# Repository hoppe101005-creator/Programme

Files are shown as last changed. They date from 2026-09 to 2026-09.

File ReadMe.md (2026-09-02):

# T4_1000 Alexander Hoppe
    Test von Elektromotoren als Alternative zum Bestehenden Motor in Kraft-
    spannblöcken und Nullpunktspannsystemen

# Benutzungsfreigabe
    Dieses Repository darf ausschließlich zur Bewertung durch die DHBW 
    Ravensburg oder zur weiteren Arbeit durch die H.-D. SCHUNK GmbH & 
    Co. Spanntechnik KG. gelesen und benutzt werden. 

# Gliederung des Repositories
    3D Druckdateien Vorrichtung:
        Hier sind alle Dateien für den 3D-Druck des Versuchsaufbaus abgelegt

    Datenblätter:
        Hier liegen alle Datenblätter, die im Laufe der Arbeit benutzt wurden

    Dokumentation:
        Hier liegen die eigentliche T4_1000 mit beiden Praxisreflektionen als 
        PDF und eine Übersicht der Motoren, die während der Arbeit in der 
        engeren auswahl waren

    Programme:
        Hier liegt das vollständige Programm zur ansteuerung der verschie-
        denen Motoren über die EPOS4-Steuerung
    
    Rohdaten Messung sofern aufgenommen:
        Hier sind Screenshots aus dem Pythonprogramm, Aufnahmen der Ströme 
        mit dem Oszilloskop und eine Zusammenfassung aller Messdaten

# Voraussetzungen
    Software:
        Python 3.14
        PyGame 
        Epos Studio

    Hardware:
        Umgebautes NSE-E mini 90-25 IOL mit Motoratrappe und Prüfstand
        Laptop mit Ethernet-Schnittstelle
        SPS mit Funktionsbaustein zum Sensordaten auslesen
        Messglocke
        Oszilloskop
        Netzgerät 24V

# Verwendung
    Clone das Repository und arbeite ausschließlich in deinem lokalen 
    Repository. Passe die lokalen Speicherorte im Code an.
    Baue den Versuch auf und Starte das Programm mit der Datei Visu.py.

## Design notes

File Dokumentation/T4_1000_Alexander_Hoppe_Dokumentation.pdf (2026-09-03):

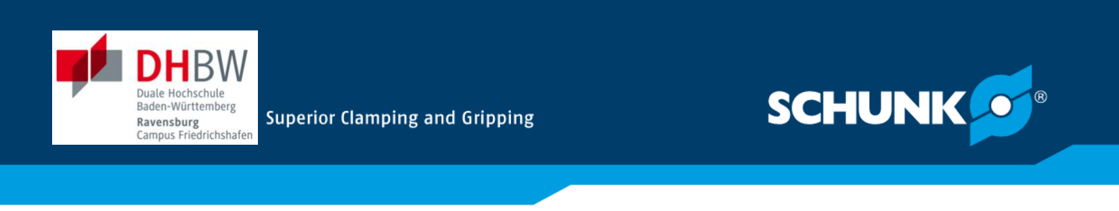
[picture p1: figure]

PRAXISBERICHT

## Test von Elektromotoren als Alternative zum beste-

## henden Motor in Kraftspannblöcken und Null-

## punktspannsystemen

des Studienganges Elektrotechnik und Informationstechnik – Automation

an der Dualen Hochschule Baden-Württemberg Friedrichshafen

von

Alexander Hoppe

05.10.2026

Bearbeitungszeitraum | 9 Wochen
Matrikelnummer, Kurs | 6516453, TEA-25
Dualer Partner | H.-D. SCHUNK GmbH & Co. Spann- technik KG Lothringer Str. 23 88512 Mengen
Betreuer*in des Dualen Partners | B. Eng. Matthias Soziev

T4_1000

II

## Sperrvermerk

Gemäß Ziffer 1.1.13 der Anlage 1 zu §§ 3, 4 und 5 der Studien- und Prüfungsordnung

für die Bachelorstudiengänge im Studienbereich Technik der Dualen Hochschule Ba-

den-Württemberg vom 29.09.2017 in der Fassung vom 25.07.2018:

„Der Inhalt dieser Arbeit darf weder als Ganzes noch in Auszügen Personen außerhalb

des Prüfungsprozesses und des Evaluationsverfahrens zugänglich gemacht werden,

sofern keine anders lautende Genehmigung vom Dualen Partner vorliegt.“

Mengen, den 03.09.2026

Alexander Hoppe

III

## Eidesstattliche Erklärung

Gemäß Ziffer 1.1.13 der Anlage 1 zu §§ 3, 4 und 5 der Studien- und Prüfungsordnung

für die Bachelorstudiengänge im Studienbereich Technik der Dualen Hochschule Ba-

den-Württemberg vom 29.09.2017.

Ich versichere hiermit, dass ich meine Bachelorarbeit (bzw. Projektarbeit oder Studi-

enarbeit bzw. Hausarbeit) mit dem Thema:

Test von Elektromotoren als Alternative zum bestehenden Motor in

Kraftspannblöcken und Nullpunktspannsystemen

selbstständig verfasst und keine anderen als die angegebenen Quellen und Hilfsmittel

benutzt habe. Ich habe bei der Erstellung der Arbeit KI-Werkzeuge eingesetzt. Dies

habe ich an den entsprechenden Stellen der Arbeit kenntlich gemacht.

Mengen, den 03.09.2026

Alexander Hoppe

IV

## Kurzfassung

Ziel dieser Projektarbeit ist es, das erlernte Wissen der ersten und zweiten Theorie-

phase mit den praktischen Inhalten zu verknüpfen und anzuwenden, aber auch gene-

rell über den Inhalt der beiden Praxisphasen zu berichten. Die erste Praxisphase war

zum Teil ein Grundkurs im Umgang mit Metall in der Lehrwerkstatt, in dem das Feilen,

Gewindebohren, Sägen und weitere maschinelle Bearbeitungsarten von Stahl vermit-

telt wurden. In der zweiten Praxisphase durfte ich in der Entwicklung mitarbeiten und

den Versuch zum Tittel dieser Arbeit durchführen.

Im ersten Teil dieser Arbeit werde ich das Unternehmen SCHUNK vorstellen, auf die

Entstehung, Geschichte, und Produktpalette eingehen, damit ein Gefühl für das Un-

ternehmen entsteht.

Anschließend liegt der Fokus auf den erlernten Fertigkeiten aus der Lehrwerkstatt im

Bereich Trennen, wie zum Beispiel das Drehen und Fräsen. Den Kern dieser Arbeit

bildet der Versuch zur Ermittlung verschiedener Alternativen zum aktuell verbauten

Maxon-Motor im Nullpunktspannsystem NSE-E mini 90-25 IOL. Hierbei wird bei einem

bestehenden Exemplar der Motor ausgebaut und die zu testenden Motoren über einen

eigens dafür entworfenen Versuchsaufbau an das Nullpunktspannsystem angebaut.

Ziel des Versuchs ist es, über die Spannkraftmessung die Eignung des Motors zu zei-

gen.

Eine Auflistung meiner Tätigkeiten in den ersten beiden Praxisphasen bei SCHUNK

bildet den Abschluss dieser Arbeit. Diese zeigt auf, welche Fähigkeiten während dieser

Zeit eingesetzt und welche Kompetenzen vermittelt wurden.

V

## Abstract

The aim of this project report is to link and apply the theoretical knowledge acquired

during the first and second semesters with practical experiences, as well as to review

the content of both practical phases. The first practical phase included a basic me-

talworking course in the training workshop, covering filing, tapping, sawing, and various

mechanical machining processes for steel. During the second practical phase, I colla-

borated with the research and development department and conducted the experiment

central to this paper.

The initial section of this report introduces SCHUNK, detailing its origins, history, and

product portfolio to provide comprehensive insight into the company. Subsequently, the

focus shifts to manufacturing skills acquired in the workshop, particularly in machining

processes such as turning and milling.

The core of this work consists of an experiment designed to evaluate various alterna-

tives to the currently installed Maxon motor in the NSE-E mini 90-25 IOL zero-point

clamping system. In this process, the motor of an existing unit is removed, and the test

motors are connected to the clamping system using a custom-designed experimental

setup. The objective of the experiment is to demonstrate the suitability of the alternative

motors through precise clamping force measurements. A detailed list of my activities

during the first two practical phases at SCHUNK concludes this report, highlighting the

skills deployed and competencies developed over this period.

VI

## Inhaltsverzeichnis

Abbildungsverzeichnis | VIII
Tabellenverzeichnis | IX
Verzeichnis von Abkürzungen, Formeln, Formelzeichen und Maßeinheiten | X
Abkürzungen | X
Formeln | X
Formelzeichen | X
Maßeinheiten | XI

VII

7 Anhang | A

VIII

## Abbildungsverzeichnis

Abbildung 15: Diagramm: Spannkräfte der verschiedenen Motoren, eigene Darstellung

Abbildung 16: Diagramm: Messwerte der Motorströme beim Spannen, eigene Darstel-

Abbildung 17: Diagramm: Messwerte der Maximalströme beim Lösen, eigene Darstel-

IX

## Tabellenverzeichnis

Tabelle 2: Messwerte des Maximalstroms beim Spannen, eigene Darstellung ........ 28

X

## Verzeichnis von Abkürzungen, Formeln, Formel-

## zeichen und Maßeinheiten

Abkürzungen

CAD | Computer-Aided Design / Computerunterstütztes Konstruieren
CNC | computerisierte numerische Steuerung
KI | Künstliche Intelligenz
RJ45 | registered Jack
u. A | unter Anderem
USB | universal serial Bus

Formeln

Formel 1: Drehmomentkonstante (Dr. Fritz Faulhaber GmbH & Co. KG 2026)........ 21

Formel 3: Drehzahl-Drehmoment-Kennlinie (Dr. Fritz Faulhaber GmbH & Co. KG 2026)

Formelzeichen

I | Strom
kM | Drehmomentkonstante
kn | Drehzahlkonstante
M | abgegebenes Drehmoment
MA | mögliches Anlaufdrehmoment
n | abgegebene Drehzahl
n0 | Leerlaufdrehzahl

XI

U | Spannung

Maßeinheiten

〖min〗^(-1)/V | Umdrehungen pro Minute/Volt
A | Ampere
M | Hinweis auf metrisches Gewinde
mm | Millimeter
s | Sekunde
V | Volt
W | Watt

## 1 Das Unternehmen SCHUNK

1.1 Die Historie

In Lauffen am Neckar kaufte sich Firmengründer Friedrich Schunk 1945 eine Dreh-

bank, auf der er Ersatzteile für Maschinen fertigte. Als erste Produktionsstätte diente

eine umgebaute Garage, in der er durch einige hochwertige und langlebige Erfindun-

gen, wie eine Lampenschirm-Lochmaschine, schnell bekannt wurde. Durch seine cle-

vere Art bekam er zusätzlich Aufträge, wie die Fertigung in anderen Betrieben zu opti-

mieren. So wurde bei Schunk „Geht nicht, gibt’s nicht“ zu einer Kernkompetenz

(SCHUNK SE & Co. KG 2026).

1964 wurde Schunk von NSU mit der Serienfertigung von 3000 Kupplungstrommeln

und Schwungscheiben für den NSU-Prinz 4 beauftragt und zog mit seiner Produktion

in einen großen Hallenneubau am heutigen Standort in Lauffen am Neckar. Von dort

an war sein Sohn Heinz-Dieter Schunk auch im Unternehmen und baute einen eigenen

Vertrieb für die Produkte von Schunk auf. Mit diesem Vertrieb gab es eine Plattform,

für die ab 1966 produzierten Standartbacken für Drehfutter (SCHUNK SE & Co. KG

2026).

Durch weitere Erfindungen, wie die Hydrodehnspanntechnik im Werkzeughalter Tendo

oder die Werkzeugspannung durch Verformung mit Hilfe der Polygonspanntechnik im

Werkzeughalter Tribos, entwickelte sich das Unternehmen zu einem kompetenten

Partner für Werkzeugspannung in der Metallverarbeitenden Industrie (SCHUNK SE &

Co. KG 2026).

Dem aktuellen Firmeninhaber Heinz-Dieter Schunk war und ist bewusst, dass man nur

durch Neuentwicklungen vorankommt. Mit diesem Grundgedanken im Hinterkopf be-

merkte Schunk auf einer Messe im Jahr 1982, dass die damaligen Greifer an den Ro-

botern zu schwer waren, und entwickelte daraufhin eigene, leichtere Greifer. Mit dieser

Entwicklung stieg SCHUNK in den zukunftsweisenden Bereich der Automation ein.

1989 entschied man sich bei SCHUNK in den Bereich der stationären Spanntechnik

einzusteigen und entwickelte hierbei das erfolgreiche TANDEM-System der Kraft-

spannblöcke (SCHUNK SE & Co. KG 2026).

Die ersten Niederlassungen im Ausland, intern als Intec bezeichnet, wurden 1989 in

Belgien und der Schweiz gegründet. In den 1990er Jahren ergab sich die Möglichkeit

durch einen steigenden Absatz in Nordamerika, einen weiteren Produktionsstandort in

Raleigh, der Hauptstadt von North Carolina, zu eröffnen (SCHUNK SE & Co. KG

2026).

1994 übernahm SCHUNK die Hage GmbH in Mengen und erweiterte somit die Pro-

duktpalette um die Drehfutter und deren Patente, die bis heute Anwendung in den Pro-

dukten des Unternehmens finden (u. A. Backenschnellwechsel im Rota THW 3)

(SCHUNK SE & Co. KG 2026).

2006 ergab sich die Möglichkeit in Hangzhou, China, ein Werk für den dortigen Markt

zu eröffnen. Die deutschen Qualitätsstandards und Ansprüche wurden allerdings nicht

erfüllt, sodass das Werk drei Jahre später geschlossen wurde. Im Gegenzug wurde

die bestehende Niederlassung in Shanghai zu einem Vertriebsstandort ausgebaut (Wi-

kipedia-Autoren 2025).

Die Magnetspanntechnik ist durch die Beteiligung mit 49% am italienischen Unternehmen S.P.D. seit 2008 Bestandteil von SCHUNK. Mit der vollständigen Übernahme von

S.P.D. vertreibt SCHUNK unter deren Namen weiterhin Magnetspanntechnik (Wikipe-

dia-Autoren 2025).

Mit einem neuen Slogan „Superior Clamping and Gripping” hielt 2012 ein neuer Mar-

kenbotschafter, der Ex-Nationaltorhüter Jens Lehmann, bei SCHUNK Einzug und be-

warb für sieben Jahre diverse Produkte von SCHUNK. Hierbei stand die Perfektion der

Produkte und Lösungen im Vordergrund. Mit einem neuen Slogan „Hand in Hand for

tomorrow“ liegt ab 2022 der Fokus auf der Automation und der Zusammenarbeit von

Mensch und Maschine als Zukunftstechnologien.

2014 übernahm SCHUNK das Schweizer Unternehmen Gressel, welches mechani-

sche Spannmittel produziert. Auch diese Marke besteht bis heute (Wikipedia-Autoren

2025).

Nach Baubeginn 2019 wurde das Werk Mengen 2020 mit der Produktionshalle 4 und

dem Entwicklungsgebäude um rund 50% vergrößert. 2022 kam die Mensa hinzu, in der die Mitarbeiter und Besucher am Standort täglich mit frisch zubereitetem Essen

versorgt werden (Joost 2025).

1.2 Werte der Firma SCHUNK

Die Firma Schunk steht für folgende Werte (SCHUNK SE & Co. KG 2026):

Klarheit

Kümmerer-Kultur

Pioniergeist

Qualität

Wertschätzung

Zuverlässigkeit

Klarheit:

Mit einem Überblick über den Markt und dem Blick nach vorn lösen wir die Probleme

der Zukunft.

Kümmerer-Kultur:

Wir kümmern uns um unsere Kunden, bis sie endgültig zufrieden sind

Pioniergeist:

SCHUNK setzt durch Entwicklungen neue Maßstäbe in den Bereichen, von denen wir

Ahnung haben. Darum machen wir nicht alles, aber was wir machen, meistern wir mit

Bravour.

Qualität:

Weil wir unsere Produkte für jahrelange Standzeiten in den Produktionen unserer Kun-

den entwickeln, hat Qualität oberste Priorität. Dahinter stecken viel Erfahrung und Wis-

sen aus jahrelanger Produktion und der Ansporn, immer besser zu werden.

Wertschätzung:

Bei SCHUNK stehen die Maschinen im Mittelpunkt, die Menschen aber an erster

Stelle. Mit gegenseitiger Wertschätzung und gegenseitigem Respekt arbeitet hier tag-

täglich jeder mit jedem an unseren Produkten: Hand in Hand for tomorrow

Zuverlässigkeit:

Unsere Produkte sind nur so gut, wie die Menschen, die sie produzieren, vertreiben

und reparieren. Darum setzt SCHUNK auf Verbindlichkeit, Sorgfalt und ein Wort, das

gilt.

1.3 Standorte

Schunk ist ein weltweit vertretenes Unternehmen mit insgesamt rund 3700 Mitarbeitern

in 10 Werken und 34 Ländern, die sich in zwei größere Untergruppen gliedern lassen

(SCHUNK SE & Co. KG 2026). Zum einen gibt es die produzierenden Standorte, zum

anderen die vertreibenden Standorte. Unter den produzierenden Standorten kann man

zusätzlich in Werke und Tochterunternehmen, die dem Standort Lauffen unterstehen,

und Werke, die dem Standort Mengen unterscheiden (Joost 2025):

Hauptsitz: Lauffen am Neckar | Brackenheim-Hausen

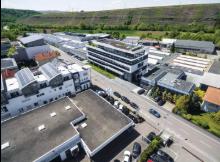
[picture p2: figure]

Abbildung 1: Hauptsitz: Lauffen am

Neckar (SCHUNK SE & Co. KG 2026)

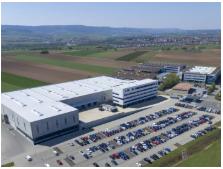
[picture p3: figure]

Abbildung 2: Werk: Brackenheim-Hau-

sen (SCHUNK SE & Co. KG 2026)

Morrisville / North Carolina (USA) | Queretaro (Mexiko)

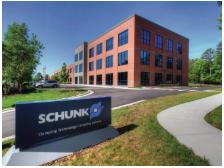
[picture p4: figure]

Abbildung 3: Werk: Morrisville (SCHUNK

SE & Co. KG 2026)

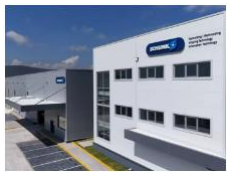
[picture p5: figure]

Abbildung 4: Werk: Queretaro (SCHUNK

SE & Co. KG 2026)

Shanghai (China) | Cleebronn

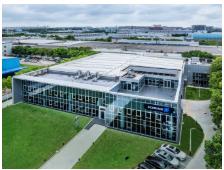
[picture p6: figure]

Abbildung 5: Werk: Shanghai (SCHUNK

SE & Co. KG 2026)

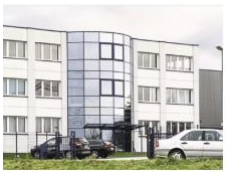
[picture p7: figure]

Abbildung 6: Eberhardt GmbH & Co. KG.

Cleebronn (SCHUNK SE & Co. KG

2026)

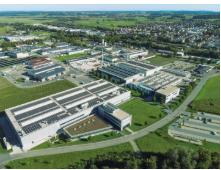
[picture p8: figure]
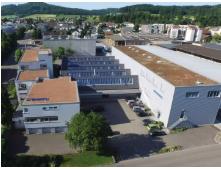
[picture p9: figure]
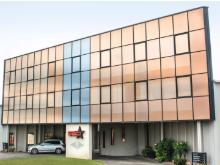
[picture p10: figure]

Zum Vertriebsnetz von Schunk zählen neben den produzierenden Standorten auch die

ausländischen Niederlassungen (Intecs). Allein in Europa gibt es in 38 von 47 souve-

ränen Staaten eine SSCHUNK-Intec oder einen Vertriebspartner. Auch in Asien ist

SCHUNK mit 20 Vertriebsstandorten in 14 Ländern vertreten, um für seine Kunden da

zu sein. Die restlichen 17 Vertriebsstellen verteilen sich auf die beiden amerikanischen

Kontinente, Australien und Südafrika (SCHUNK SE & Co. KG 2026).

Mengen | Gressel AG in Aadorf (Schweiz)

Abbildung 7: Werk: Mengen (SCHUNK

SE & Co. KG 2026)

Abbildung | 8: | Gressel AG: Aadorf

(SCHUNK SE & Co. KG 2026)

S.P.D.-Werk in Caravaggio (Italien)

Abbildung 9: S.P.A.: Caravaggio

(SCHUNK SE & Co. KG 2026)

1.4 Produkte

SCHUNK bietet Produkte in folgenden Bereichen an:

Automatisierungstechnik

Greiftechnik

Nutzentrenntechnik

Werkstückspanntechnik

Werkzeugspanntechnik

In der Automatisierungstechnik bietet SCHUNK eine Vielzahl an Lösungen und

Standardkomponenten an. Wenn es um die Bewegung entlang einer Achse oder um

eine Achse geht, sind die Linearachsen oder die Schwenkeinheiten das Mittel der

Wahl. Damit die Baugruppen nicht überlastet werden, verbaut SCHUNK Kraft-Moment-

Sensoren, die während des Betriebs, zum Beispiel an einem Roboterarm zwischen

Arm und Greifer, die auftretenden Kräfte und Momente messen. In Verbindung mit der Robotersteuerung kann man in diesem Fall eine Überlastsicherung realisieren. An ei-

nem Roboterarm müssen oft verschiedene Greifer für verschiedene Anwendungen an-

gebaut werden - mit den Werkzeugwechslern von SCHUNK kein Problem. Um unter

Bewegung keine Verbindung zu verlieren, gibt es auch Kabeldurchführungen, sowohl

starr als auch schwenkbar. Die Ausgleichseinheiten von SCHUNK kommen immer

dann zum Einsatz, wenn man Abweichungen in Bewegungsabläufen kompensieren

muss. In Kombination mit den SCHUNK-Greifern kann über verschiedene Applikati-

ons-Kits eine lageunabhängige Robotersteuerung realisiert werden, welche:

die Werkstücke greift

an eine rotierende Polierbürste hebt

dort zielgerichtet das Werkstück poliert

anschließend das Werkstück in einer Kiste absetzt

(SCHUNK SE & Co. KG 2026).

Die Greiftechnik wird zum größten Teil in Brackenheim-Hausen gefertigt und dort in

Verbindung mit einem CoLab, einem Vorführungsraum, erprobt und präsentiert. Die

Greifer werden in verschiedenen Formen für verschiedenste Anwendungen entworfen.

Es gibt Parallelgreifer, die mit zwei Fingern entlang einer Achse verfahren, Zentrisch-

greifer, die wie ein Dreibackenfutter einer Drehmaschine mit ihren Fingern das Werk-

stück zentriert greifen, aber auch Winkel-/Radialgreifer, die ihre beiden Finger um ei-

nen fixen Punkt öffnen und schließen. Daneben gibt es Greifer mit Schwenkeinrich-

tung, die sich um ihre eigene Achse bewegen können, und Magnetgreifer, die durch

Elektromagneten magnetische Werkstücke fassen. Hinzu kommen sämtliche Sonder-

greifer und Adhäsionsgreifer, die nach dem Vorbild eines Geckos ihre Werkstücke

sanft und rückstandsfrei greifen (SCHUNK SE & Co. KG 2026).

Nutzen sind große Leiterplatten, die durch Nutzentrenntechniken in kleinere Platinen

geteilt werden. Um diesen Vorgang möglichst effektiv zu gestalten, baut SCHUNK Nut-

zentrenner als Stand-Alone-Lösung, aber auch als Maschinen für eine Produktions-

straße. Damit die Nutzen nicht durch die Maschine beschädigt werden, stellt SCHUNK

zusätzlich auch die passenden Werkstückträger her und das alles in St. Georgen

(SCHUNK SE & Co. KG 2026).

Wenn es um die Werkstückspanntechnik geht, kommt man bei SCHUNK nicht am

Werk Mengen und den Tochterunternehmen Gressel und S.P.D. vorbei. Gressel stellt

die manuell betätigten Spannsysteme, S.P.D. die komplette Magnettechnik und

SCHUNK Mengen die ganzen Drehfutter, Kraftspannblöcke, Nullpunktspannsysteme

und stationären Spannsysteme her. Im weiteren Verlauf werden die Testreihen an ei-

nem elektrisch betriebenem Nullpunktspannsystem durchgeführt (SCHUNK SE & Co.

KG 2026).

Am Hauptsitz in Lauffen wird ein Großteil der Werkzeugspanntechnik gefertigt. Da-

runter fallen Hydrodehnspannfutter, bei denen der Schaft des Werkzeughalters durch

eine Druckkammer verengt wird und das Werkzeug klemmt. Die Polygonspannfutter

funktionieren durch Verformung. Im entspannten Zustand ist der Schaft des Halters

nicht exakt rund, sondern etwas dreieckig. Durch hohen Druck von außen verformt

sich der Schaft zu einem Kreis und das Werkzeug kann eingelegt werden. Anschlie-

ßend nimmt man den Druck weg und das Werkzeug verkanntet sich im Schaft. Die

Drehspannfutter funktionieren über einen Konus, der zusammengedreht wird, sodass

das Werkzeug klemmt. Das Gleiche passiert, wenn ein Warmschrumpffutter von

SCHUNK erhitzt wird, das Werkzeug eingelegt wird und es wieder abkühlt. Die

Spannzangen spannen das Werkzeug über verschiedene konische Einsätze, die vom

Schaftdurchmesser des Werkzeugs abhängen (SCHUNK SE & Co. KG 2026).

## 2 Spanende Fertigungsverfahren

Die verschiedenen Fertigungsverfahren lassen sich nach DIN 8580 in sechs Haupt-

gruppen wie folgt gliedern:

| Beschichten: Aufbringen einer fest haftenden Schicht Fügen: Zwei Bauteile werden miteinander verbunden Trennen: Material wird abgetragen Stoffeigenschaften ändern: Materialeigenschaften werden durch äußere Einflüsse verändert Umformen: Herstellen eines Bauteils allein durch äußere Krafteinwirkung Urformen: Herstellen eines Bauteils durch Erhitzen, in Form füllen und Abkühlen

Ein spanendes Fertigungsverfahren bezeichnet das Abtragen des überschüssigen Ma-

terials von einem Rohteil in Form von Spänen, um ein bestimmtes Maß oder eine vorgegebene Kontur herzustellen und gehört somit in die Hauptgruppe Trennen (Öhler Sj

2022/23).

2.1 Grundbegriffe

Um im weiteren Verlauf die Fertigungsverfahren, die in der Lehrwerkstatt gezeigt wur-

den, erklären zu können, bedarf es an dieser Stelle der Definition einiger Grundbe-

griffe:

Kühlschmierstoff:
Kühlschmierstoffe bestehen meist aus Öl und Wasser und sind dazu da, um bei

Zerspanungen Werkstück und Werkzeugschneide zu kühlen und zu schmieren.

Bei der Schnittbewegung entsteht durch Reibung Hitze, die die Schneide ohne

ausreichende Kühlung zum Glühen bringt und sie stumpf macht. Die Wärme wird primär durch die anfallenden Späne abtransportiert, kann aber auch durch

den Einsatz von Kühlschmierstoffen verringert werden. Mit ausreichender Küh-

lung kann die Wärme abgeleitet und so die Standzeit der Schneide des Werk-

zeugs erhöht werden. Bei leichter Zerspanung liegt der Fokus auf der Kühlung, weshalb man hier auf einen hohen Wasseranteil im Öl-Wasser-Gemisch setzt.

Bei schwerer Zerspanung braucht man die Schmierwirkung des Kühlschmierstoffs und setzt auf einen hohen Öl-Anteil (Brendle 2025).

Schlichtbearbeitung:

Beim Schlichten geht es darum, die endgültigen Maße, Toleranzen und Ober-

flächen herzustellen. Daher verwendet man zum Schlichten oft auch andere

Werkzeuge als zum Schruppen (Brendle 2025).

Schnittbewegung:

Bei einer Schnittbewegung bewegen sich Werkzeugschneide und Werkstück

durch den Vorschub anfangs aufeinander zu, bevor die Schneide in das Werk-

stück eintaucht, Späne bildet und so Material abträgt.

Schnittbreite:

Die Schnittbreite bezieht sich auf die Position des Werkzeugs relativ zur Posi-

tion des Werkstücks. Konkret: Wie weit taucht die Schneide meines Werkzeugs

entlang der Werkstückoberfläche in das Werkstück ein (Hanser Sj 2022/23).

Schnittgeschwindigkeit:

Unter der Schnittgeschwindigkeit versteht man die Geschwindigkeit, die die

Schneide am entferntesten Punkt zum Werkzeugmittelpunkt während der

Schnittbewegung hat (Hanser Sj 2022/23).

Schnitttiefe:

Die Schnitttiefe bezieht sich auf die Position des Werkzeugs relativ zur Position

des Werkstücks. Konkret: Wie weit taucht die Schneide meines Werkzeugs

senkrecht zur Werkstückoberfläche in das Werkstück ein (Hanser Sj 2022/23).

Schruppbearbeitung:

Beim Schruppen liegt das Hauptaugenmerk auf dem schnellen Abtragen es

überschüssigen Materials. Daher kann man hier mit ungenaueren Werkzeugen

arbeiten (Brendle 2025).

Standzeit:

Die Standzeit bezeichnet die Lebensdauer eines Werkzeugs oder in diesem

Zusammenhang die Lebensdauer einer Schneide (Brendle 2025).

Vorschub:

Der Vorschub bezeichnet die Bewegung, die der Werkzeugmittelpunkt relativ

zum Werkstück entlang der zu bearbeitenden Kontur hat (Hanser Sj 2022/23).

Wendeschneidplatten:

Eine Wendeschneidplatte ist ein flaches Element mit mehreren Schneiden zur

Befestigung auf einem Werkzeug. Durch die vielen Schneiden ist es möglich

die Wendeschneidplatte, bei Verschleiß einer Schneide, zu drehen und sie so

länger zu nutzen.

Werkstücknullpunkt:

Der Werkstücknullpunkt ist ein Referenzpunkt, von wo aus das Werkstück be-

maßt wird. Er wird nach dem Einspannen des Rohlings in der Maschine einge-

messen, und muss mit dem Nullpunkt der Zeichnung übereinstimmen. Andern-

falls muss der Werkstücknullpunk so verschoben werden, dass er dem Null-

punkt der Zeichnung entspricht (Brendle 2025).

Zerspanbarkeit:

Die Zerspanbarkeit bezeichnet die Widerstandsfähigkeit eines Werkstoffs wäh-

rend der Zerspanung. Sie hängt von unterschiedlichen Faktoren, wie den Werk-

stoffeigenschaften, ab und zeigt sich in der Oberflächengüte, Standzeit der

Werkzeuge und am Brechen der Späne (Brendle 2025).

Zustellung:

Als Zustellung wird das Maß bezeichnet, das während des Arbeitsgangs durch

die Späne verloren geht (Brendle 2025).

2.2 Drehen

Das Drehen ist eines der essenzielle Fertigungsverfahren im Maschinenbau, da hier

sehr leicht Rotationskörper bearbeitet werden können. Hierbei trägt eine feststehende

Werkzeugschneide eine vorgegebene Kontur entlang eines rotierenden Werkstücks

ab, sodass die zweidimensionale Kontur als Rotationskörper entsteht. Die

Rotationsachse ist durch das Drehfutter der Drehbank vorgegeben. Hierbei kann nicht

immer sofort auf das Endmaß der Kontur zugestellt werden, da jedes Werkzeug mit

jedem Werkstoff unterschiedlich interagiert und die Schneide, selbst unter Verwen-

dung des Kühlschmierstoffs, oft überhitzen würde. Daher nimmt man einen Großteil

der Späne mit der Schruppbearbeitung ab und stellt den Rest in mehreren Schritten

mit der Schlichtbearbeitung zu. Die Schneidewerkzeuge werden oft als Drehmeißel

bezeichnet und sind in der Regel mit einer Wendeschneidplatte an der Spitze bestückt.

Durch die einzelne Schneide findet eine kontinuierliche Spanabnahme statt, was in der

Lehrwerkstatt sichtbar wurde. Auch bei SCHUNK stehen viele Drehmaschinen, die

meisten mit einer CNC-Steuerung, um zum Beispiel die Rohlinge der Drehfutter oder

Werkzeughalter zu fertigen.

2.3 Fräsen

Das Fräsen ist auch essenziell für die Fertigung im Maschinenbau, da hier ebene Flä-

chen und gerade Kanten sehr leicht hergestellt werden können. Hierbei wird das Werk-

stück auf dem Tisch der Fräsmaschine eingespannt und ein Fräser, das Schneidwerk-

zeug der Fräse, bewegt sich mit Hilfe des Vorschubs relativ zum Werkstück durch das

Werkstück. Bei CNC-gesteuerten Fräsmaschinen hinterlegt man eine Zeichnung und

den Werkstücknullpunkt, wonach die Fräsmaschine eine Art Laufkarte errechnet und

diese abfährt. Bei konventionellen Maschinen erledigt das der Bediener. Auch hier

schruppt man zuerst die groben Konturen, bevor man sie schlichtet. Wie beim Drehen

kann man durch Einsatz von Kühlschmierstoffen die Standzeit des Fräsers bezie-

hungsweise die Standzeit der Wendeschneidplatten des Fräsers verlängern. Fräsen

haben, im Unterschied zu den Drehwerkzeugen, immer mehrere Schneiden für einen

ruhigeren Lauf. Als Faustformel kann man sagen: Je genauer das Maß oder die Ober-

fläche, desto mehr Schneiden. Die Schneiden sind immer gleichmäßig über die Stirn-

seite verteilt und schlängeln sich entlang der Mantelfläche des Fräsers hinauf zum

Schaft des Fräsers. Das hat zur Folge, dass jede Schneide innerhalb einer Umdrehung

einmal aus dem Werkstück aus- und einmal in das Werkstück eintritt. Dadurch kann

sich kein kontinuierlicher Span bilden. Fräsmaschinen sind ein sehr großer und wichtiger Bestandteil der Produktion bei SCHUNK, da auf diesen Maschinen sämtliche

Körper von Produkten gefertigt werden.

2.4 Bohren

Das Bohren ist dem Fräsen sehr ähnlich, weil auch hier der Bohrer rotiert, um den

Span aus dem Bohrloch zu schneiden und das Werkstück fixiert ist. Der Vorschub zeigt

entlang der Achse des Bohrers, der durch seine Geometrie eine kontinuierliche Span-

abnahme ermöglicht. Ein Spiralbohrer, das Schneidwerkzeug beim Bohren, verfügt

über drei Schneiden, die punktsymmetrisch über sie Bohrspitze verteilt sind: Die Quer-

schneide verläuft senkrecht zum Bohrerschaft durch den Mittelpunkt der Bohrspitze

und bohrt im Durchmesser rund ein Drittel des Materials des Bohrdurchmessers um

den Mittelpunkt auf. Die restlichen zwei Drittel des Bohrlochs verteilen sich zu je einer

Hälfte auf eine Hauptschneide. Die Hauptschneiden stehen in einem bestimmten Win-

kel zum Schaft, nicht senkrecht wie beim Fräser, und haben zusätzlich einen Winkel

zur Querschneide bei der Projektion aller drei Schneiden auf die Ebene, die senkrecht

zum Schaft des Bohrers verläuft. Zusätzlich besitzt er zwei Nebenschneiden, die sich

entlang der Wendel von der Spitze zum Schaft schlängeln. Mit Bohrern werden Löcher

mit definierten Durchmessern hergestellt, die bestimmte Toleranzen, sowohl im Durch-

messer als auch in der Oberflächengüte der Mantelfläche, haben. Möchte man ein

Loch mit einer höheren Maßhaltigkeit, muss man das Loch kleiner vorbohren und an-

schließend reiben.

2.4.1 Reiben

Das Reiben ist eine spezielle Form des Bohrens, mit dem Ziel eine bestehende Boh-

rung mit einem genormten Maß auf ein größeres genormtes Maß zu weiten. Hierbei

liegt der Fokus auf der Maßhaltigkeit und der Oberflächengüte der Bohrung, die man

benötigt, um eine Passung herzustellen. Die Schnittgeschwindigkeit von Bohrern wird

beim Reiben halbiert, da hier ein ruhiger Lauf für die Maßhaltigkeit entscheidend ist.

Der Bohrer beim Reiben wird als Reibahle bezeichnet und es gibt ihn in mehreren

Ausführungen:

Mehrschneidig, nicht einstellbar

Mehrschneidig, einstellbar im Durchmesser

Einschneidig mit Führungsleiste, einstellbar im Durchmesser

2.4.2 Senken

Auch das Senken ist eine Art des Bohrens, nur wird hierbei ein Profil an der Stirnseite

einer bestehenden Bohrung hinzugefügt. Die gängigsten Anwendungen sind Kegel-

senkungen oder Zylindersenkungen. Bei Kegelsenkungen wird mit einem Kegelsen-

ker, ein mehrschneidiger Bohrer mit einem Kegel als Profil, bis zu einer definierten

Tiefe in das Loch gebohrt. Durch die Kegelform zentriert er sich selbst. Bei einer Zy-

lindersenkung hat man die Form eines Bohrers, dessen Spitze senkrecht zur Bohrer-

achse abgeschnitten und ihm ein Zentrierdorn in der Mitte aufgesetzt hat. Damit die

Zylindersenkung konzentrisch zur Bohrung ist, besitzt der Zylindersenker zusätzlich

einen Zentrierbolzen an der Stelle der Querschneide eines Bohrers. Darüber hinaus

sind weitere Konturen möglich, aber äußerst selten.

## 3 Messen

3.1 Was ist messen?

Definition nach DIN 1319-1 (Manghard 2026):

Messen ist das Ausführen von geplanten Tätigkeiten zum quantitativen Vergleich der

Messgröße mit einer Maßeinheit

3.2 Warum misst man?

Die Ingenieursweisheit „Wer misst, misst Mist“ geht auf Murphys-Gesetz zurück und

verdeutlicht, dass eine einzelne Messung meist nicht ausreicht, um ein zuverlässiges

Ergebnis zu erhalten. Ein einzelner Messwert kann durch Messfehler beeinflusst wer-

den und somit stark vom theoretischen Wert abweichen. Deshalb sollte man mehrere

Messungen durchführen und die Ergebnisse miteinander vergleichen. Aus mehreren

Messwerten lässt sich ein Bereich bestimmen, in dem der tatsächliche Wert liegt. Je

mehr sorgfältige Messungen vorgenommen werden, desto zuverlässiger und genauer

wird das Ergebnis (Manghard 2026). Liegen nur wenige Messwerte vor und weichen

diese stark voneinander ab, lässt sich kaum beurteilen, welcher Wert dem tatsächli-

chen Wert am nächsten kommt. Genau auf diese Unsicherheit spielt die Weisheit „Wer

misst, misst Mist“ an.

3.3 Messmittel

Messmittel sind Messwerkzeuge zur Ermittlung eines Messwerts. Jedes Messmittel

besitzt eine Auflösung und einen Messbereich:

Auflösung:

Als Auflösung wird der Abstand zwischen zwei benachbarten, kleinstmöglichen

Messwerten bezeichnet. Abhängig von der geforderten Genauigkeit der Mes-

sung erfolgt die Wahl des Messmittels (Manghard 2026).

Messbereich:

Der Messbereich eines Messmittels beschreibt den Bereich, in dem alle

Messwerte des Messmittels liegen (Manghard 2026).

3.3.1 Messschieber

Der Messschieber ist im Maschinenbau ein grundlegendes Messmittel, um Längen von

Strecken zu messen. Ein Messschieber misst nach der Ausschlagmethode. Dabei ver-

schiebt sich die bewegliche Messbacke (Abbildung 10: Standardmessschieber, (Wiki-

media 2023)) entlang einer Skala (Abbildung 10: Standardmessschieber, (Wikimedia

2023)Ziffer 4) und die Nullmarkierung, beziehungsweise die Noniusskala (Abbildung

10: Standardmessschieber, (Wikimedia 2023)Ziffer 6) erzeugt den Ausschlag. Duch

eine spezielle Anordnung der Noniusskala, kann man hiermit bei einem analogen

Messschieber eine Auflösung von 0,1 mm erzielen. Bei digitalen Messschiebern funk-

tioniert das ganze nach dem gleichen Prinzip, nur über einen elektronischen Weg-

sensor. Das Signal des Wegsensors wird anschließend in die gewünschte Maßeinheit

umgerechnet. Die meisten digitalen Messschieber verfügen über eine Nulltaste, mit

der man einen neuen Referenzpunkt bei einem bestimmten Maß setzen kann, wenn

man zum Beispiel nur die Differenz zweier Längen haben möchte und nicht das abso-

lute Maß. Messschieber gibt es in verschiedenen, an diverse Anwendungen ange-

passte, Bauformen:

Standardmessschieber:

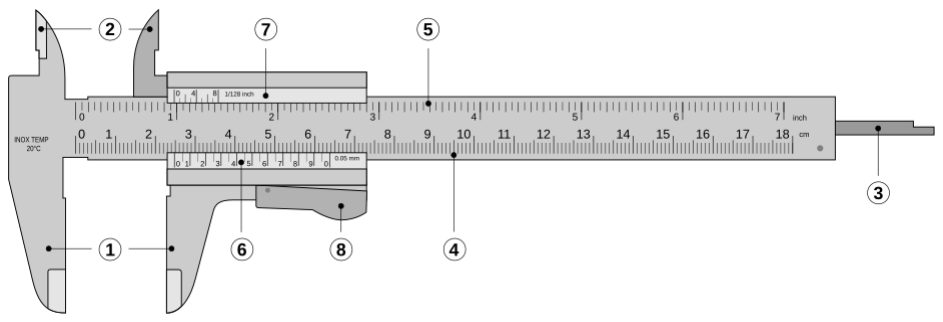
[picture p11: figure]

Abbildung 10: Standardmessschieber, (Wikimedia 2023)

Der Standardmessschieber hat drei Möglichkeiten Längen zu messen: Es gibt

an dem festen und dem losen Teil je zwei fixe Backen, ein Paar für die

Längenmessung außerhalb des Bauteils (Abbildung 10: Standardmessschie-

ber, (Wikimedia 2023)), das andere für die Längenmessung innerhalb des Bau-

teils (Abbildung 10: Standardmessschieber, (Wikimedia 2023)). Die dritte Mög-

lichkeit ist der Messdorn auf der Unterseite (Abbildung 10: Standardmessschie-

ber, (Wikimedia 2023)Ziffer 3). Mit ihm kann man einen Falz oder die Tiefe einer

Bohrung oder einer Nut vermessen (Brendle 2025).

Tiefenmessschieber:

Mit dem Tiefenmessschieber misst man Längen zwischen einer Ebene und ei-

nem Punkt durch ein Loch in der Ebene. Dabei setzt man den Tiefenmessschie-

ber mit dessen Füßen auf der Ebene auf und lässt den Messdorn auf den zu

messenden Punkt fallen (Brendle 2025). Das gleiche kann man auch mit einem

Standardmessschieber machen. Die Messung ist allerdings nicht so genau, weil

der Standardmessschieber eine kleinere Auflagefläche auf der Ebene hat und

man so leichter verwackelt.

3.3.2 Bügelmessschraube

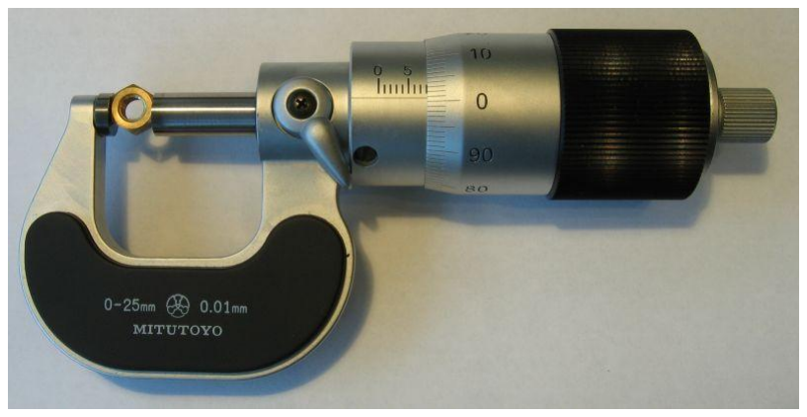
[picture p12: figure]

Mit der Bügelmessschraube misst man

Strecken um Bauteile herum mit einer

höheren Auflösung als mit einem Mess-

schieber, weil die Bügelmessschraube

anders aufgebaut ist. Die Bügelmess-

schraube misst auch nach der Aus-

schlagmethode und funktioniert über ei-

nen Messbolzen, der durch ein festste-

hendes Außengewinde gedreht wird. Da-

bei verfährt der Bolzen bei einer Umdrehung um einen durch die Gewindesteigung definierten Wert. Über zwei Skalen kann man den Messwert ablesen: Entlang des

Messbolzen ist die grobe Skala zur Bestimmung der Messgröße im Millimeterbereich

aufgetragen. Durch das Verdrehen des Bolzens bewegt sich eine Art Hülse über die

Außenseite des feststehenden Gewindes. Auf der Mantelfläche dieser Hülse ist die

Abbildung 11: Bügelmessschraube, (wiki-

media 2010)

feinere Skala mit einer höheren Auflösung zur Feinbestimmung abgebildet (Abbildung

11: Bügelmessschraube, (wikimedia 2010)). Den Messwert liest man ab, indem man

den groben Wert am Rand der Hülse und den feinen Wert durch Verlängerung des

Fluchtstrichs der Grobskala auf die Feinskala abliest. Mit einer normalen Bügelmess-

schraube erreicht man eine Auflösung von 0.01 mm (Brendle 2025).

3.3.3 Multimeter

Zum Messen verschiedener elektrischer Größen ist das Multimeter das Mittel der

Wahl. Mit ihm lassen sich zum einen verschiedene Spannungen und Ströme, aber

auch Widerstandswerte ermitteln. Das Multimeter besitzt drei Anschlüsse, von denen

bei jeder Messung zwei benutzt werden. Bei einer Spannungsmessung liegt auf einem

Anschluss das Referenzpotential, auf dem anderen Anschluss das zu messende Po-

tential. Bei einer Strommessung wird gezählt, wie viel Ladung pro Zeit fließt, daher

benötigt man bei einer Strommessung auch beide Anschlüsse. Den Anschluss für das

zu messende Signal wählt man in Abhängigkeit des Messbereichs, die Masse ist aber

immer belegt. Bei der Widerstandsmessung finden intern beide anderen Messungen

statt und das Messgerät verrechnet nur die Einzelwerte miteinander (Gerster 2026).

3.3.4 Oszilloskop

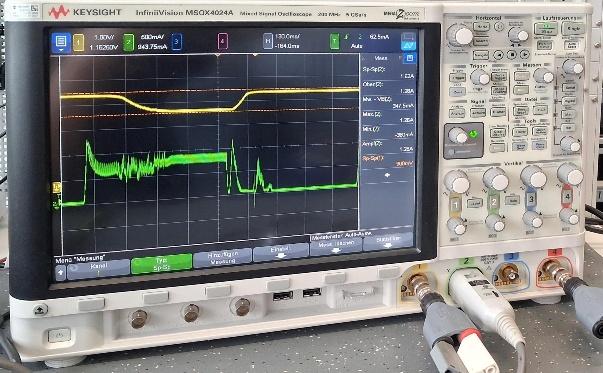
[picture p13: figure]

Mit dem Oszilloskop lassen sich Spannungs-

verläufe beobachten und analysieren. Das Os-

zilloskop braucht für jedes Signal ein Signalpo-

tential und ein Referenzpotential, da die Span-

nung immer eine Potentialdifferenz ist. Nun

wird das Signal auf dem Bildschirm in einem

u(t)-Diagramm angezeigt und man kann zu

verschiedenen Zeiten verschiedene Span-

nungswerte ablesen. Wenn das Gerät mehrere

Signaleingänge hat, kann man die einzelnen Signale übereinanderlegen, um Abwei-

chungen festzustellen. Falls das Signal einer Funktion ähnelt, können manche

Abbildung 12: Oszilloskop, eigene

Darstellung

Oszilloskope eine Näherungsfunktion bestimmen, mit der man rechnen kann (Gerster

2026).

3.3.5 Hall-Sensor

Um den Hall-Sensor zu verstehen, muss man zuerst verstehen, was der Hall-Effekt ist.

Fließt Strom durch einen Leiter, erzeugt er ein kreisförmiges Magnetfeld um den Leiter.

Ist dieser Leiter flexibel in einem anderen homogenen Magnetfeld, werden durch die

Lorenzkraft die Elektronen im Leiter bewegt, weil sich beide Felder überlagern.

Dadurch, dass die Elektronen nicht aus dem Leiter heraus können, bewegt sich der

Leiter senkrecht zur Stromrichtung und zum homogenen Magnetfeld. Tauscht man den

Leiter gegen einen Quader und fixiert diesen, so kann man die Bewegung der Elektro-

nen als Hall-Spannung messen (Dr. Hellwig Sj 2023/24). Diesen Effekt nutzt ein Hall-

Sensor, um die Lage eines Magnetfelds und dessen Stärke zu bestimmen. Diese Sen-

soren nutzt man in bürstenlosen Gleichstrommotoren, um die Lage des Magnetfelds

zu bestimmen und anschließend die Kommutation, also die Umpolung des Magnet-

felds innerhalb eines Motors, zu steuern.

3.3.6 Piezoelektrische Sensoren

Sensoren, die den piezoelektrischen Effekt nutzen, können äußere Kräfte in ein Span-

nungssignal umwandeln, weil sie im Inneren eine Kristallstruktur besitzen. In dieser

Struktur gibt es Elektronen und Protonen, die sich durch ihre unterschiedliche Ladung

anziehen und so zwei Ladungsschwerpunkte innerhalb des Kristalls bilden. Wird der

Kristall durch eine Kraft verformt, verschieben sich die Ladungsschwerpunkte und es

entsteht eine sehr kleine Spannung innerhalb eines Kristalls (FWU Institut für Film und

Bild in Wissenschaft und Unterricht gemeinnützige GmbH 2026). Durch Skalieren vie-

ler Kristalle verstärkt sich der Effekt und es entsteht eine messbare Spannung. Mit

dieser Art Sensor wird im weiteren Verlauf die Einzugskraft und somit die Eignung der

verschiedenen Motoren überprüft.

## 4 Motorversuch

4.1 Problemstellung

In den elektromechanischen Nullpunktspannsystemen von SCHUNK werden aktuell

Motoren verbaut, die vom Zulieferer Maxon ausschließlich an schon bestehende Kun-

den und nicht mehr an Neukunden verkauft werden. Daher vermuten wir, dass die

Produktion dieser Motoren auf Dauer eingestellt wird und das Nullpunktspannsystem

einen neuen Motor braucht (Briemle 2026). Das Problem ist nur, dass es wenige bürs-

tenlose „Motoren von der Stange“ gibt, die genügend Leistung haben, aber trotzdem

in das Produkt integriert werden können. Das Schwierigste dabei sind die Höhe des

Motorkörpers, der Wellendurchmesser und die Flanschmaße der anderen Hersteller.

4.2 Aufbau und Funktion des Nullpunktspannsystems

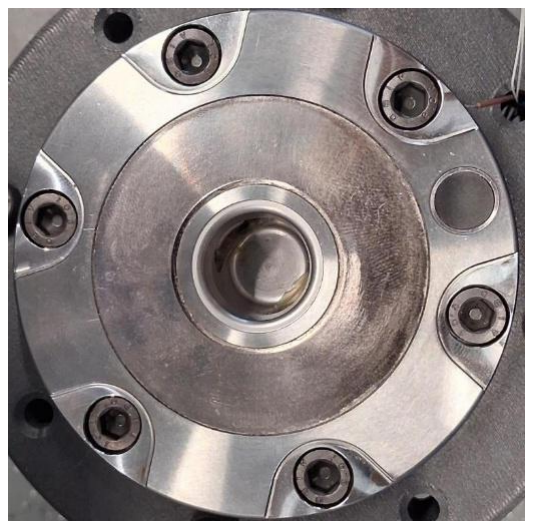
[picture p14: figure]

Über das Spannloch in der Mitte der Oberseite

nimmt das Nullpunktspannsystem einen Spann-

bolzen auf und spannt diesen über zwei Spann-

schieber. Durch die geometrische Form von

Spannschieber, Spannloch und Spannbolzen

kann der Spannbolzen mit rund 3kN eingezogen

werden (SCHUNK SE & Co. KG 2026).

Das Nullpunktspannsystem (Abbildung 13: Null-

punkspannsystem, eigene Darstellung) wird aktu-

ell von einer Baugruppe, bestehend aus einem

bürstenlosen Flachmotor mit 50W und einem Zykloidgetriebe von SCHUNK mit einer Übersetzung von 1:400 angetrieben. Der Abtrieb

des Getriebes ist mit einer Scheibe, in welche eine Kurvenbahn eingefräst ist, verbun-

den. Auf dieser Scheibe sind zwei geführte Bolzen, die beim Verdrehen der Scheibe

entweder öffnen oder schließen und den Spannbolzen des zu spannenden Objekts

einziehen. Das heißt, dass mit jeder Umdrehung sich die Spannkraft erhöht. Möchte

man nun eine vorgegebene Spannkraft erreichen, muss man die entsprechende

Abbildung 13: Nullpunkspann-

system, eigene Darstellung

Position der geforderten Spannkraft herausfinden. Daher wird im folgenden Versuch

die Position in ganzen Umdrehungen angegeben.

4.3 Spezielle Kennwerte eines Motors

Jeder Motor hat seine eigenen charakteristischen Eigenschaften, wonach man ver-

schiedene Motoren vergleichen kann. Einige davon sind ausschlaggebend für den Ver-

wendungszweck in den verschiedenen Produkten. In diesem Fall geht es hauptsäch-

lich darum, viel Kraft zu erzeugen. Dafür braucht man ein hohes Drehmoment, was

durch die Drehung der Kurvenbahn in eine Kraft umgewandelt wird. Dieses Drehmo-

ment entsteht durch Lorenzkraft. Die Lorenzkraft beschreibt die Kraft, die in einem

stromdurchflossenen Leiter in einem Magnetfeld gemäß der Linken-Hand-Regel auf

ein Elektron wirkt. Dabei zeigt der Daumen den Elektronenfluss, also von Minus nach

Plus, der Zeigefinger entlang der Magnetfeldlinien, von Nord nach Süd, und der Mittel-

finger zeigt in die Richtung der resultierenden Lorenzkraft. Kurz gesagt: Das Drehmo-

ment des Motors entsteht aus der Elektronenbewegung, also aus dem elektrischen

Strom. Um diese Umwandlung quantitativ vergleichen zu können, gibt es die Drehmo-

mentkonstante. Diese Drehmomentkonstante berechnet sich wie folgt:

Formel 1: Drehmomentkonstante (Dr. Fritz Faulhaber GmbH & Co. KG 2026)

kM =

M
I
kM: | Drehmomentkonstante
M: | abgegebenes Drehmoment
I: | Strom

Je höher dieser Wert ist, um so effektiver ist die Energieumwandlung von elektrischer

Energie über magnetische Energie in kinetische Energie.

Die Drehzahlkonstante ist ein wichtiger Kennwert für die Ansteuerung des Motors, da

sie über das Verhältnis von Spannung zu Drehzahl Auskunft gibt. Durch sie kann man

für jede Leerlaufdrehzahl den dazugehörigen Spannungswert wie folgt berechnen:

Formel 2: Drehzahlkonstante (Dr. Fritz Faulhaber GmbH & Co. KG 2026)

kn =

n
U
kn: | Drehzahlkonstante
n: | abgegebene Drehzahl
U: | Spannung

Je niedriger dieser Wert ist, um so feinfühliger lässt sich die Leerlaufdrehzahl für jede

Spannung einstellen. Natürlich schwindet ein Teil der Drehzahl durch die Belastung im

Arbeitsfall.

Um beide Konstanten miteinander zu verknüpfen, gibt es die Drehzahl-Drehmoment-

Kennlinie. Anhand dieser Kennlinie kann man den Drehzahlabfall bei steigender Last,

also steigendem Drehmoment am Abtrieb des Motors, beschreiben und beobachten.

Diese Kennlinie beginnt bei Leerlaufdrehzahl ohne Lastmoment und endet beim maxi-

malen Anlaufmoment, das der Motor überwinden kann. Rein rechnerisch gibt es zwei

Achsenschnittpunkte, die aber in der Realität durch Reibung und andere Gegebenhei-

ten nicht existieren. Daraus ergibt sich folgende Formel:

Formel 3: Drehzahl-Drehmoment-Kennlinie (Dr. Fritz Faulhaber GmbH & Co. KG 2026)

n = −

∆n
∆M

∗ M + n0

n = −

n0 − n
M

∗ M + n0

Steigungsdreieck aus den Achsenschnittpunkten:

n = −

n0
MA

∗ M + n0

Ausklammern von n0 ergibt:

n = n0 ∗ (1 −

M
MA

)

n: | abgegebene Drehzahl
n0: | Leerlaufdrehzahl
M: | abgegebenes Drehmoment
MA: | mögliches Anlaufdrehmoment

Diese Formel verdeutlicht den Zusammenhang zwischen den beiden Größen und den

theoretischen Achsenschnittpunkten, ablesbar durch die beiden Konstanten Leerlauf-

drehzahl und Anlaufdrehmoment. Diese beiden Achsenschnittpunkte sind nicht mög-

lich, da das Drehmoment aus dem elektrischen Strom und die Drehzahl aus der Span-

nung hervorgeht und beide elektrischen Größen in der Realität, durch reale Bauteile,

nicht getrennt voneinander auftreten können. Daher wird oft in Datenblättern nur die

Steigung dieser Kennlinie angegeben.

Um den Motor vor Überhitzung zu schützen, gibt es Grenzwerte für die Umgebungs-

temperatur, bei der ein Motor betrieben werden darf. Zur Umgebungstemperatur hinzu

kommen zwei verschiedene thermische Zeitkonstanten τ, die Auswirkungen auf die

Temperatur im Motor haben. Die thermische Zeitkonstante des Motors ist ein Maß für

die thermische Trägheit des Motors bei Erwärmung und Abkühlung. Sie gibt an, nach

welcher Zeit sich der Motor um rund 63% erwärmt hat (Dr. Fritz Faulhaber GmbH &

Co. KG 2026). Eine hohe Zeitkonstante bedeutet eine hohe Trägheit und eine lange

Zeit bis der Motor seine Genztemperatur erreicht hat. Da der Graph bis zum Erreichen

der Grenztemperatur einer Exponentialfunktion ähnelt, kann man in Bereich von 0 <

t < 5τ den Graph annähernd durch solch eine Funktion beschreiben. Die gleiche Me-

thode existiert auch für die einzelnen Wicklungen. Da alle Wicklungen innerhalb des

Motors baugleich sind und sich somit gleich erwärmen, wird die Bestimmung nur an

einer Wicklung durchgeführt.

4.4 Auswahl der Motoren

Bei der Auswahl der Motoren gibt es drei Bereiche, die über die Eignung entscheiden:

Anschlüsse:

Der Motor wird mit einer fixen Versorgungsspannung betrieben. Diese Versor-

gungsquelle darf nicht überlastet werden und liefert daher nur einen bestimmten

Strom. Zur Ansteuerung der Kommutation benötigt die aktuelle Steuerung das Signal der Hall-Sensoren im Innenraum des Motors. Über die drei Hall-Senso-

ren bestimmt man die Lage des Magnetfeldes und dadurch die Lage von Rotor

und Stator zueinander. Damit können die einzelnen Spulen so angesteuert wer-

den, dass sich der Motor dreht.

Bauraum:

Der Bauraum entscheidet darüber, ob der Moror an dem vorgesehenen Platz in

die Baugruppe passt. Dafür muss der Flansch zum Fügen des Motors in die

Baugruppe zur Gegenseite des Motors passen.

Spezielle Kennwerte eines Motors:

Die speziellen Kennwerte geben Auskunft über die Umwandlung der elektri-

schen Energie in mechanische Energie.

Das hier benutzten Nullpunktspannsystem von SCHUNK gibt folgende Werte vor

(SCHUNK SE & Co. KG 2026):

Anschlusswerte:

Betriebsspannung: 24V

Maximale Stromaufnahme: 3A

Leistung: rund 45W (Vorgängermotor)

Bauraum:

Durchmesser: <45mm

Länge Motorkörper: <25mm

Lochkreis Flansch: ∅22mm, 3 Gewindelöcher M3 (120° zueinander verscho-

ben)

Welle: ∅4mm

Zentrierdurchmesser: ∅12mm

Spezielle Kennwerte eines Motors:

Drehmomentkonstante: 78.6mNm/A Drehzahlkonstante: 121min⁻¹
/V

Thermische Zeitkonstanten:

Motor: 78.30s

Wicklung: 28.80s

Steigung der Drehmoment-Drehzahl-Kennlinie: 5.58min⁻¹
/mNm

Nach einiger Recherche und ein paar Absprachen habe ich mich für folgende Motoren

entschieden:

ACT 57BL03-1: Bauraum zu klein, aber preiswert

Faulhaber 4221 G024 BXT R: erfüllt alle Voraussetzungen

Delta Line 45BLW21: erfüllt, nach Anpassungen, alle Voraussetzungen

Maxon EC 45 flat (651613), zu ersetzender Motor als Referenz

4.5 Versuchsaufbau

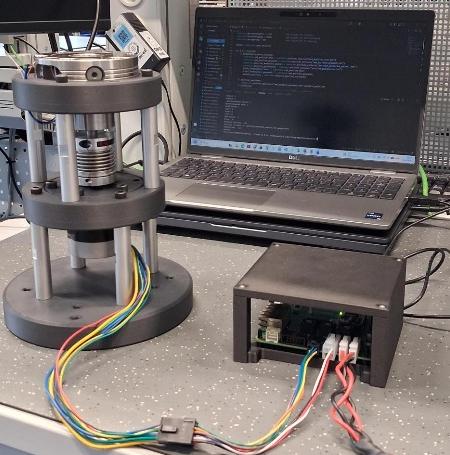
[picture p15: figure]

Für diesen Versuch wird ein NSE-E mini 90-25 IOL mit

einer Motorattrappe zur Verfügung gestellt. Nun wird

eine Vorrichtung in der CAD-Software Creo Parametric

entworfen, 3D-gedruckt und nach Rücksprache mit Sven

Briemle entschieden, eine Kupplung und Abstandshül-

sen als Kaufteil zu erwerben. Durch die verschiedenen

Durchmesser müssen Buchsen gedreht werden, um die

Kupplung kraftschlüssig mit den Wellen der verschiede-

nen Motoren zu verbinden. Die verschiedenen Motoren

werden an dafür konstruierte Flanschplatten ange-

schraubt. Die Einzugskraft wird von einer Messglocke,

ausgebaut aus einem internen Prüfstand, mit dem piezoelektrischen Kistler Kraftmess-

ring 9102C gemessen, der Strom mit der Strommesszange eines Oszilloskops. Zur

Ansteuerung wird die EPOS4 Motorsteuerung und zum Auslesen der Sensordaten, der

Position und der Bedienung ein eigenes Programm in Python verwendet. Um die Mo-

toren mit der Motorsteuerung ansteuern zu können, muss man die passende Steck-

verbindung motorseitig herstellen, die Motorsteuerung mit der Betriebsspannung des

Motors versorgen und sie über USB oder RJ45 / Ethernet mit dem Laptop verbinden.

Abbildung 14: Versuchsauf-

bau ohne Messgeräte, ei-

gene Darstellung

4.6 Erläuterungen zum Vorgehen

Vorab muss gesagt werden, dass die Spannposition der Motoren im Nullpunktspann-

system aktuell über eine Kombination aus dem Strom und der Position definiert wird.

Damit im Versuch gleichbleibende Bedingungen für alle Motoren herrschen, werden

hier die verschiedenen Positionen ausschließlich über die Anzahl der Umdrehungen

definiert. Im folgenden Unterkapitel wird beschrieben, wie man auf die Messfälle

kommt. Die acht Messfälle bilden sich aus drei Parametern, die jeweils zwei Zustände

erreichen können:

Position:

Die Position soll bei allen Motoren im Versuch die gleiche sein, um sie miteinan-

der vergleichen zu können. Daher muss man die Position in Inkrementen in eine

Position in vollständigen Umdrehungen umrechnen. Um die Werte der einzel-

nen Positionen zu ermitteln, dreht wird der Antrieb des Nullpunktspannsystems

händisch von Endanschlag zu Endanschlag gedreht (Geöffnet, Geschlossen).

Möchte man die Zwischenpositionen, dreht man diesen Abtrieb so weit zu, dass

entweder der Spannbolzen sich gerade noch, ohne zu verhaken entnehmen

lässt (Wechsel) oder man mit eingesetzter Messglocke die geforderte Spann-

kraft erreicht (Gespannt).

Drehzahl:

Die Drehzahlen wurden so gewählt, dass sie von den Motoren erreicht werden

und das Nullpunktspannsystem innerhalb von rund drei Sekunden verfährt.

Bremsbeschleunigung:

Die Bremsbeschleunigung wurde so gewählt, dass es keine ruckartigen Ab-

bremsungen gibt und die Motoren trotzdem ruhig anhalten. Damit können de

Positionen genauer angefahren werden.

4.7 Durchführung

Nachdem das Nullpunktspannsystem und der zu testende Motor in der Vorrichtung

platziert wurden, legt man an die Motorsteuerung die Betriebsspannung des Motors

an, hinterlegt die Kennwerte des Motors in der Software der Steuerung und startet das

Python-Programm in einer dafür geeigneten Programmierumgebung. Dort gibt man

Motor, Position der Spannschieber, Drehzahl und die positive / negative Beschleuni-

gung an. Danach kann man durch Klicken auf einen der angezeigten Buttons die

Spannschieber an die programmierten Positionen verfahren. Die Messung der Ein-

zugskraft erfolgt nur während des Spannprozesses. Nach einer Wartezeit von zehn

Sekunden nach Stillstand der Spannschieber endet die Spannkraftmessung und die

Spannschieber fahren wieder auf die Wechsel-Position. Anschließend wird noch zwei

weitere Male gespannt, um mögliche Abweichungen vom ersten Messwert auszu-

schließen. Nach jeder Messung wird die Betriebsspannung abgeschaltet, um jede

Messung unter den gleichen Voraussetzungen durchzuführen. Damit die Einflüsse der

jeweiligen Eingabeparameter getestet werden, durchläuft jeder Motor mehrmals mit

geänderten Parametern diesen Prozess. Getestet werden der Einfluss des Bremsbe-

schleunigung, der Drehzahl und der Position und es ergeben sich folgende Ergeb-

nisse:

Tabelle 1: Messwerte der Spannkraft, eigene Darstellung

Messfall | Position | Drehzahl | Bremsbeschleuni-gung | Spannkraft
| | | | ACT | Faulhaber | Maxon
| [1] [ | 1 ] min | 1 [ ] 2 s | [kN] | [kN] | [kN]
1 | 30 | 1500 | 275 | 2,8 | 2,8 | 2,5
2 | 30 | 1500 | 150 | 2,8 | 2,8 | 2,5
3 | 30 | 1000 | 275 | 2,8 | 2,8 | 2,6
4 | 30 | 1000 | 150 | 2,8 | 2,7 | 2,4
5 | 31 | 1500 | 275 | 3,6 | 3,7 | 3,2
6 | 31 | 1500 | 150 | 3,6 | 3,6 | 3,2
7 | 31 | 1000 | 275 | 3,6 | 3,6 | 3,2
8 | 31 | 1000 | 150 | 3,6 | 3,6 | 3,1

## Spannkräfte

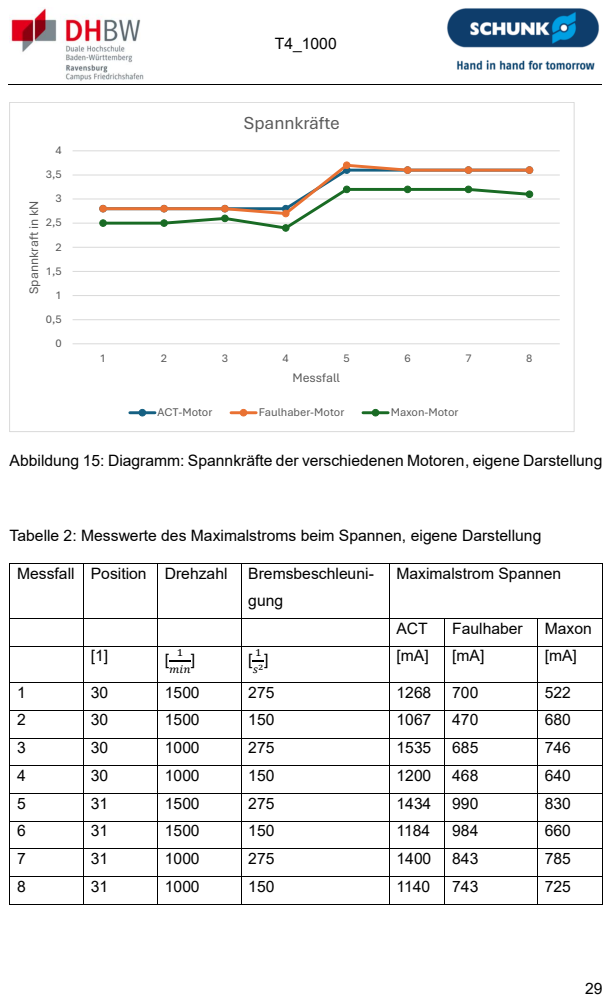
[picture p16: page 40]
Messfall; ACT-Motor; Faulhaber-Motor; Maxon-Motor

Spannkraft in kN

Abbildung 15: Diagramm: Spannkräfte der verschiedenen Motoren, eigene Darstellung

Tabelle 2: Messwerte des Maximalstroms beim Spannen, eigene Darstellung

Messfall | Position | Drehzahl | Bremsbeschleuni-gung | Maximalstrom Spannen

ACT | Faulhaber | Maxon

[1] [ | 1 ] min | 1 [ ] s 2 | [mA] | [mA] | [mA]

1 | 30 | 1500 | 275 | 1268 | 700 | 522
2 | 30 | 1500 | 150 | 1067 | 470 | 680
3 | 30 | 1000 | 275 | 1535 | 685 | 746
4 | 30 | 1000 | 150 | 1200 | 468 | 640
5 | 31 | 1500 | 275 | 1434 | 990 | 830
6 | 31 | 1500 | 150 | 1184 | 984 | 660
7 | 31 | 1000 | 275 | 1400 | 843 | 785
8 | 31 | 1000 | 150 | 1140 | 743 | 725

## Motorströme beim Spannen

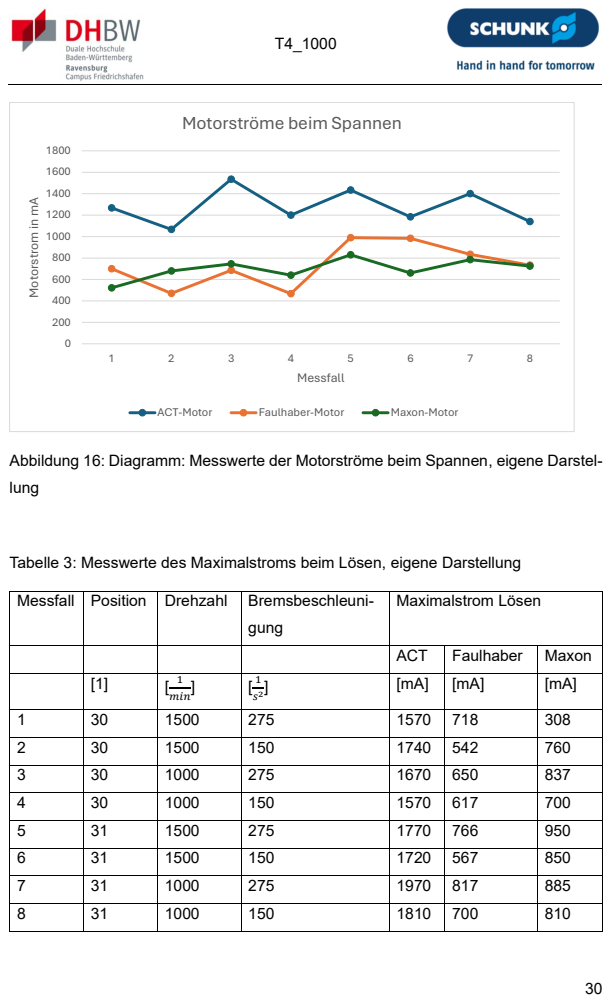
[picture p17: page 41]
Messfall; ACT-Motor; Faulhaber-Motor; Maxon-Motor

Motorstrom in mA

Abbildung 16: Diagramm: Messwerte der Motorströme beim Spannen, eigene Darstel-
lung

Tabelle 3: Messwerte des Maximalstroms beim Lösen, eigene Darstellung

Messfall | Position | Drehzahl | Bremsbeschleuni-gung | Maximalstrom Lösen

ACT | Faulhaber | Maxon

[1] [ | 1 ] min | 1 [ ] s 2 | [mA] | [mA] | [mA]

1 | 30 | 1500 | 275 | 1570 | 718 | 308
2 | 30 | 1500 | 150 | 1740 | 542 | 760
3 | 30 | 1000 | 275 | 1670 | 650 | 837
4 | 30 | 1000 | 150 | 1570 | 617 | 700
5 | 31 | 1500 | 275 | 1770 | 766 | 950
6 | 31 | 1500 | 150 | 1720 | 567 | 850
7 | 31 | 1000 | 275 | 1970 | 817 | 885
8 | 31 | 1000 | 150 | 1810 | 700 | 810

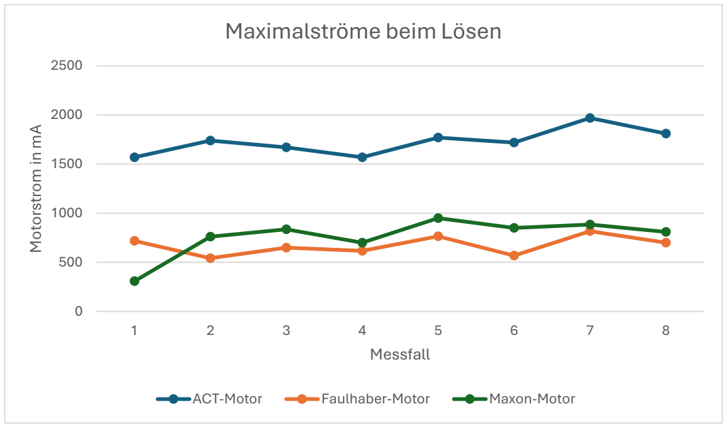
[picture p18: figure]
Motorstrom in mA; Messfall; Maximalströme beim Lösen; ACT-Motor; Faulhaber-Motor; Maxon-Motor

Abbildung 17: Diagramm: Messwerte der Maximalströme beim Lösen, eigene Darstel-

lung

Aus den Diagrammen des Oszilloskops lassen sich durch Integration verschiedene

Fahrströme berechnen. Zur Annäherung an den Graph des Stroms werden verschie-

dene Geraden in das Schaubild gelegt und anhand dieser Geraden integriert. Als

Grundlage dienen die mit dem Oszilloskop aufgenommenen Diagramme der einzelnen

Fälle mit den höchsten Maximalströmen. Die Berechnungen werde ich schrittweise am

Fall 7 während des Lösevorgangs des ACT-Motors durchführen und für die anderen

Fälle nur die Ergebnisse angeben. Die Formel wird anfangs allgemein angegeben und

in den einzelnen Schritten in kleineren Gleichungen genutzt, zuerst allgemein, danach

mit den Werten aus dem Beispiel.

Formel 4: Mittelwert des Integrals einer Geraden

Imittel =

1
t

∗ ∫ (

i(t = 3s) − i(t = 0s)
t

∗ t + i(t = 0s))

t

0

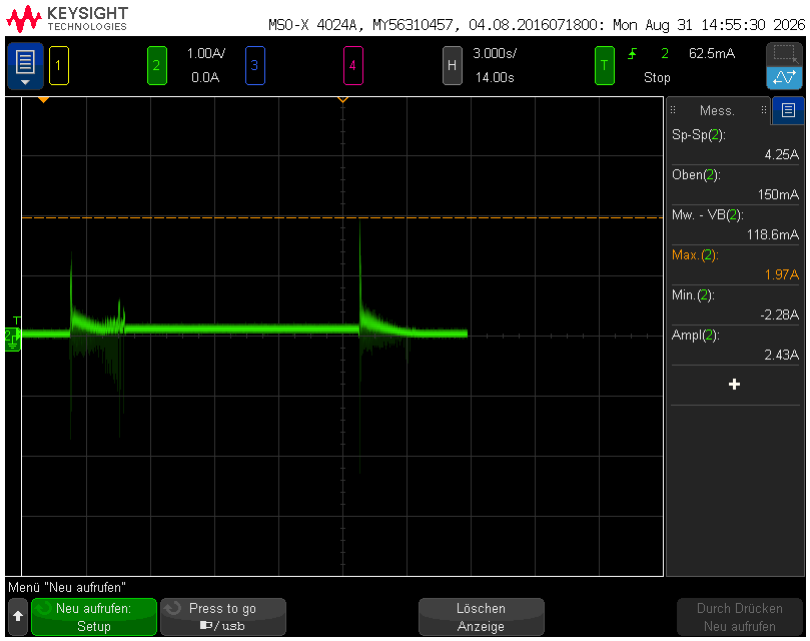
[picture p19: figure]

Abbildung 18: Oszilloskop ACT-Motor Fall 7

1. Werte aus Abbildung 18 ablesen:
t = 3s | i(t = 0s) = 450mA | i(t = 3s) = 160mA
2. i(t) als Geradengleichung bestimmen:

i(t) =

i(t = 3s) − i(t = 0s)
t

∗ t + i(t = 0s)

=

−290mA
3s

∗ t + 450m

3.

4. i(t) nach t integrieren:

I(t) =

i(t = 3s) − i(t = 0s)
2 ∗ t

∗ t

2 + i(t = 0s) ∗ t

=

−290mA
2 ∗ 3s

∗ t

2 + 450mA ∗ t

5. Das bestimmte Integral lösen:

Da die Zeit t aus Schritt 1 vom Ursprung gemessen wurde, entfällt das Einset-

zen der unteren Integrationsgrenze, da diese den Wert Null hat und bei einem

Bestimmten Integral die Integrationskonstante entfällt.

I(3s) =

−280mA
2 ∗ 3s

∗ (3s)

2 + 450mA ∗ 3s

= 915mA ∗ s

6. Den mittleren Strom berechnen:

Imittel =

I(3s)
t

=

915mA ∗ s
2.5s
= 305mA

Tabelle 4: Mittelwerte der Ströme beim Fahren

Motor | Messfall | Aktion | Imittel
| | | [mA]
ACT | 3 | spannen | 685
| 6 | lösen | 305
Faulhaber | 5 | spannen | 485
| 7 | lösen | 200
Maxon | 8 | spannen | 405
| 8 | lösen | 100

4.8 Auswertung

Eine vollständige Auswertung ist zu diesem Zeitpunkt nicht möglich, da der Motor von

DeltaLine noch nicht geliefert wurde und somit noch nicht getestet werden konnte.

Generell fällt auf, dass im Vergleich der Maxon-Motor den Spannbolzen bei jeder Mes-

sung mit einer wesentlich kleineren Spannkraft einzieht als die anderen Motoren im

Versuch. Daher sieht man, dass das Nullpunktspannsystem die erforderliche Spann-

kraft von 3kN mit dem ACT- und dem Faulhaber-Motor bei der richtigen Position (31

Umdrehungen nach der Wechselposition) übertrifft. Wenn man die Differenz der

Spannkräfte des Nullpunktspannsystems kleiner als 0,4kN zur Spannkraft des Refe-

renzmotors haben möchte, muss man die Position der Motoren über Zwischenschritte

innerhalb einer Umdrehung ansteuern. Man muss die Umdrehungen in kleinere

Schritte umrechnen, die mit den Impulsen der Hall-Sensoren zusammenhängen. Um

diesen Umrechnungsfaktor zu bestimmen, ermittelt man die Polpaarzahl, multipliziert

sie mit der Anzahl der Hallsensoren und verdoppelt diesen Wert.

Wenn man sich den Verlauf der Maximalströme in Abbildung 16: Diagramm: Mess-

werte der Motorströme beim Spannen oder in Abbildung 17: Diagramm: Messwerte

der Maximalströme beim Lösen anschaut, erkennt man einen Strom-Sockel bei jeder

Bewegung. Dieser Sockel existiert, weil sich das magnetische Feld zuerst in ausrei-

chender Stärke aufbauen muss, um den Rotor und somit die Welle zu bewegen. Wie

groß das magnetische Feld sein muss, um genügend Kraft für die Bewegung aufbrin-

gen zu können, hängt vom Trägheitsmoment des Rotors ab. Durch die größere Bau-

form des ACT-Motors sind dieses Trägheitsmoment und der daraus resultierende

Stromsockel bei diesem Motor wesentlich größer. Beim Faulhaber-Motor liegt das Ro-

torträgheitsmoment im Rahmen des Rotorträgheitsmoments des Maxon-Motors. Au-

ßerdem betragen die Mittelwerte der Fahrströme beim ACT-Motor rund das 1,5-fache

der gleichen Ströme der anderen Versuchsmotoren Tabelle 4: Mittelwerte der Ströme

beim Fahren.

Die Motoren unterscheiden sich gewaltig im Bauraum. Der ACT ist mehr als doppelt

so lang und besitzt den rund 1,5-fachen Durchmesser des Maxon-Motors. Daher eignet er sich nicht für den Einbau in das bestehende Nullpunktspannsystem. Der Faul-

haber ist kleiner als der Maxon-Motor und kann auch hier punkten. Allerdings sind die

Flanschmaße anders, sodass folgende Flanschflächen im Nullpunktspannsystem an-

gepasst werden müssen: Es müssen auf dem bestehenden Lochkreis weitere Ge-

winde gebohrt werden und der Zentrierdurchmesser muss von 12mm auf 16mm er-

weitert werden.

Daher empfehle ich den Faulhaber-Motor und werde ihn für die weitere Integration in

das Nullpunktspannsystem in Betracht ziehen.

## 5 Tätigkeitsübersicht

Tabelle 5: Tätigkeitsübersicht, eigene Darstellung

Tätigkeit | Abteilung | Zeitraum
Manuelle Grundfertigkeiten: Sicherheitsunterweisung Umgang mit Hilfs-, Mess-, Prüfmitteln und Werkzeugen Feilen, Sägen, Gewindeschneiden Technische Zeichnungen lesen und verstehen Umgang mit Kühlschmierstoffen Fügen durch Schrauben Ordnung und Sauberkeit am Arbeitsplatz | Lehrwerkstatt | KW40/25-42/25
Konventionelle Fertigung: Kenngrößen (Beispiel: Schnittgeschwindigkeit) Einstellen der Maschine Wartung der Maschine Verschleiß von Schneidstoffen Maschinelles Drehen und Fräsen | Lehrwerkstatt | KW43/25-48/25
Vorkurs Physik | DHBW | KW49/25-50/25
Grundlagen der Elektrotechnik: Kennenlernen des zukünftigen Arbeitsumfelds Löten kleiner Projekte (Beispiel: Durchgangsprüfer) Schaltschrank verschlauchen Programmieren eines Arduinos Erster Kontakt mit IO-Link | Entwicklung | KW51/25

Einarbeiten in Ingenieursaufgaben:

Messtechnik

Sensorik

Softwareprüfungen am IO-Link-Prüfstand

Einsatz von Standartsoftware zur Text- und Da-

tenverarbeitung

Beschaffung Kaufteile

Entwurf und Zeichnen eines Versuchsaufbaus

Einarbeitung in Creo Parametic und Zeichnen

von 3D-Druckteilen für den Versuchsaufbau

(4.5)

3D-Druck

Einarbeitung in Epos Studio zur Motoransteu-

erung (4.5)

Programmierung der Ansteuerung des Motor-

versuchs in Python

Entwicklung | KW 27/26-
| 39/26

## 6 Schlusswort

Die Bearbeitung dieser Arbeit war interessant für mich, weil ich Schnittstellen in der

Entwicklung zwischen Elektrotechnikern und Maschinenbauern kennengelernt habe.

Die Einarbeitung in Creo Parametric war für mich überraschend, aber interessant, da

man als Elektrotechniker eigentlich wenig Schnittpunkte mit dem Prozess bis zum fer-

tigen 3D-Druckteil hat. Beim Entwerfen des Prüfstands ist aufgefallen, dass die Spann-

kraftmessung in einem Kraftspannblock in dieser Form nicht möglich ist, da der An-

triebsstrang unvorteilhaft verbaut ist, daher die Messung am Nullpunktspannsystem.

Durch diese Arbeit habe ich auch gelernt, dass man in der Lehrwerkstatt nicht nur zum

Kennenlernen ist, sondern auch hinterher davon profitieren kann. Zu Beispiel habe ich

die Hülsen zwischen der Kupplung und den Motoren selbst gedreht, weil diese bei der

Bestellung untergegangen sind. Bei der Recherche war es hilfreich die heutigen Hilfs-

mittel zu nutzen und dadurch zu lernen, wie man möglichst zielgerichtet Anfragen an

eine künstliche Intelligenz stellt.

Das Programmieren in Python hat mich zum Teil an meine Grenzen gebracht, weil mir

die Erfahrung im Umgang mit solch umfangreichen Programmen gefehlt hat und mir

dadurch erst klar wurde, was alles möglich ist.

Im nächsten Schritt wird der Motor noch ausgiebiger getestet und versucht, den Motor

in das Nullpunktspannsystem zu integrieren und diese Kombination mit dem neuen

Zykloidgetriebe in Serie gehen zu lassen.

## Literaturverzeichnis

Brendle, Bernd. Ausbildungsbetreuer Fa. SCHUNK (2025).

Briemle, Sven, Interview geführt von Alexander Hoppe. Gespräch über Thema

T4_1000 (29. 06 2026).

Dr. Fritz Faulhaber GmbH & Co. KG. Bürstenlose DC-Motoren. 2026. https://www.faul-

haber.com/fileadmin/Import/Media/DE_TI_BRUSHLESS_DC-MOTORS.pdf

(Zugriff am 12. 08 2026).

Dr. Hellwig, Sven. „Lehrer.“ Unterrichtsmaterial Physik. Sj 2023/24.

FWU Institut für Film und Bild in Wissenschaft und Unterricht gemeinnützige GmbH.

LeifiPhysik-Piezoeffekt. 2026. https://www.leifiphysik.de/elektrizitaetslehre/la-

dungen-elektrisches-feld/ausblick/piezoeffekt (Zugriff am 24. 08 2026).

Gerster, Thomas. „Dozent .“ Vorlesungsskript Labor Digitaltechnik. 2026.

Hanser, Jochen. „Lehrer.“ praktischer Unterricht. Bertha-Benz-Schule Sigmaringen, (Sj

2022/23).

Joost, Heiko. „Abteilungsleiter Ausbildung Fa. Schunk.“ Werksführung. Mengen, (01.

09 2025).

Manghard, Rohland. „Vorlesungsskript Messtechnik 1 unveröffentlicht.“ 2026.

Öhler, Felix. „Unterrichtsskript Metaltechnik, unveröffentlicht.“ Bertha-Benz-Schule

Sigmaringen, Sj 2022/23.

SCHUNK SE & Co. KG. Automatisierungstechnik. 2026. https://schunk.com/de/de/au-

tomatisierungstechnik/c/PUB_8294 (Zugriff am 10. 08 2026).

—. Greiftechnik. 2026. https://schunk.com/de/de/greiftechnik/c/PUB_8293 (Zugriff am

10. 08 2026).

—. Historie. 2026. https://schunk.com/de/de/unternehmen/historie (Zugriff am 23. 07

2026).

—. Standorte. 2026. https://schunk.com/de/de/unternehmen/standorte (Zugriff am 24.

07 2026).

—. Über Schunk. 2026. https://schunk.com/de/de/unternehmen/ueber-schunk (Zugriff

am 22. 08 2026).

—. Übersicht NutzenTrenntechnik. 2026. https://schunk.com/de/de/produkte/nutzen-

trenntechnik/uebersicht (Zugriff am 10. 08 2026).

—. Werkstückspanntechnik - hochwertige Spanntechnik von SCHUNK. 2026.

https://schunk.com/de/de/werkstueckspanntechnik/c/PUB_8291 (Zugriff am 10.

08 2026).

—. Werkstückspannung – SCHUNK. kein Datum. https://schunk.com/de/de/werkstu-

eckspanntechnik/elektromechanische-spannsysteme/elektromechanische-null-

punktspannsysteme/nse-e-mini-90-25-iol/nse-e-mini-90-25-

iol/p/000000000001521521 (Zugriff am 12. 08 2026).

—. | Werkzeughalter | - | Werkzeugspannung | – | SCHUNK. | 2026.

https://schunk.com/de/de/werkzeugspanntechnik/werkzeughalter/c/PUB_8310

(Zugriff am 10. 08 2026).

wikimedia. | „Buegelmessschraube.“ | 22. | 11 | 2010. | https://commons.wikime-

dia.org/wiki/File:Buegelmessschraube_res.jpg (Zugriff am 01. 09 2026).

Wikimedia. „Vernier_caliper.“ 21. 03 2023. https://thumb.wikimedia.org/wikipedia/com-

mons/thumb/f/f6/Vernier_caliper.svg/1920px-Ver-

nier_caliper.svg.png?utm_source=commons.wikimedia.org&utm_cam-

paign=index&utm_content=thumbnail&_=20230521172931 (Zugriff am 01. 09

| 2026).
Wikipedia-Autoren. | Wikipedia. | 20. | 10 | 2025. | https://de.wikipe-

dia.org/wiki/Schunk_SE_%26_Co._KG (Zugriff am 22. 07 2026).

## Anmerkung zur Nutzung von Künstlicher Intelli-

## genz

Tabelle 6: KI-Nutzung, eigene Darstellung

KI-Tools | Nutzung
Gemini | technische Unterstützung bei Fragen zum Textver-arbeitungsprogramm Übersetzung der Kurzfassung Verständnisfragen
SchunkGPT | Suche von Fakten und Zusammenhängen Hinweise bei der Erstellung verschiedener Ver-zeichnisse
Microsoft Copi-lot | Unterstützung beim Programmieren

A

## 7 Anhang

Im Normalfall würden hier Datenblätter, Programmcode und vieles mehr auftauchen.

Weil das aber den Umfang dieses Dokuments sprengt, gibt es nachfolgend den Link

zu einem Repository auf Github, wo meine ganzen Materialien abrufbar sind, die ich

zur Erstellung dieser Arbeit verwendet habe.

Link zum Repository: Repository: T4-1000-Alexander-Hoppe (https://github.com/hoppe101005-creator/T4-1000-Alexander-Hoppe)

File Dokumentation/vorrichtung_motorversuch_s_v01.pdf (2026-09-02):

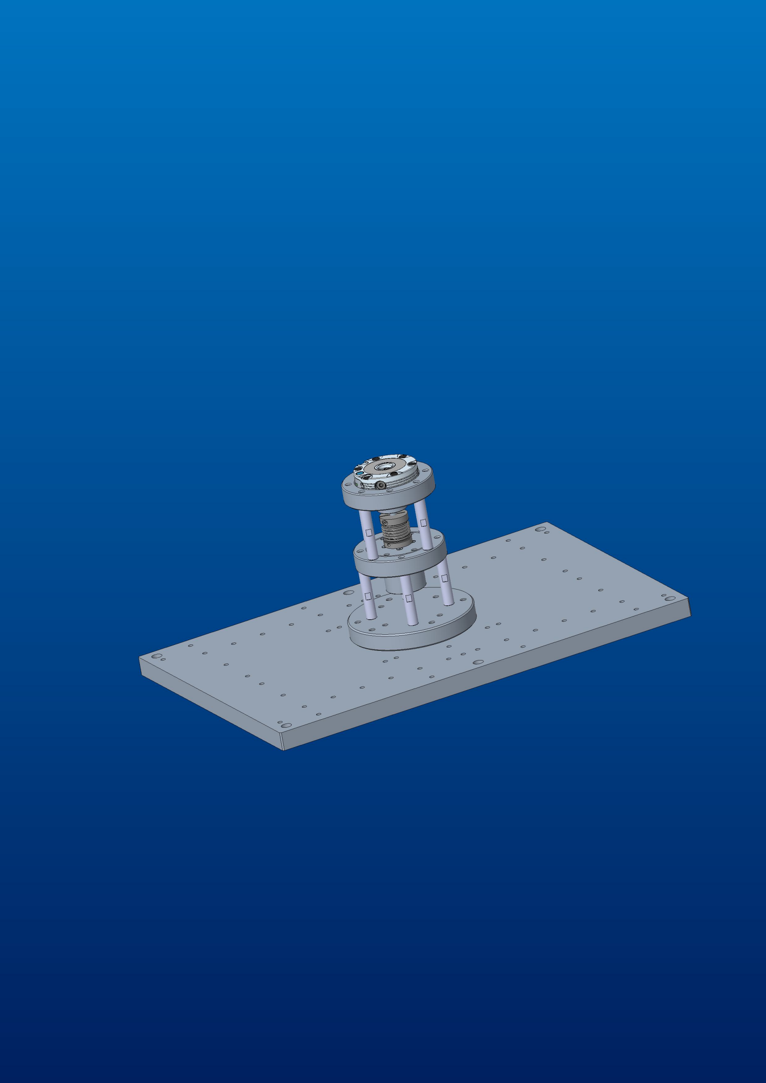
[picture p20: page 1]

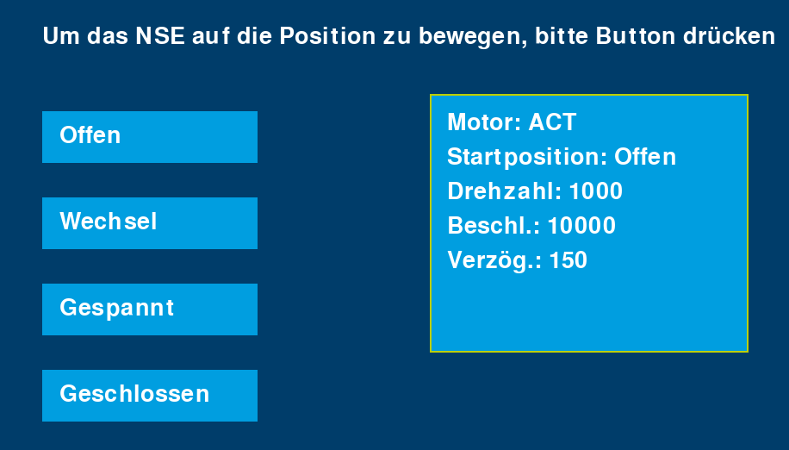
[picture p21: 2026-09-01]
Rohdaten Messung sofern aufgenommen/Messungen ACT/Messung 6 2026-08-27 114330.png

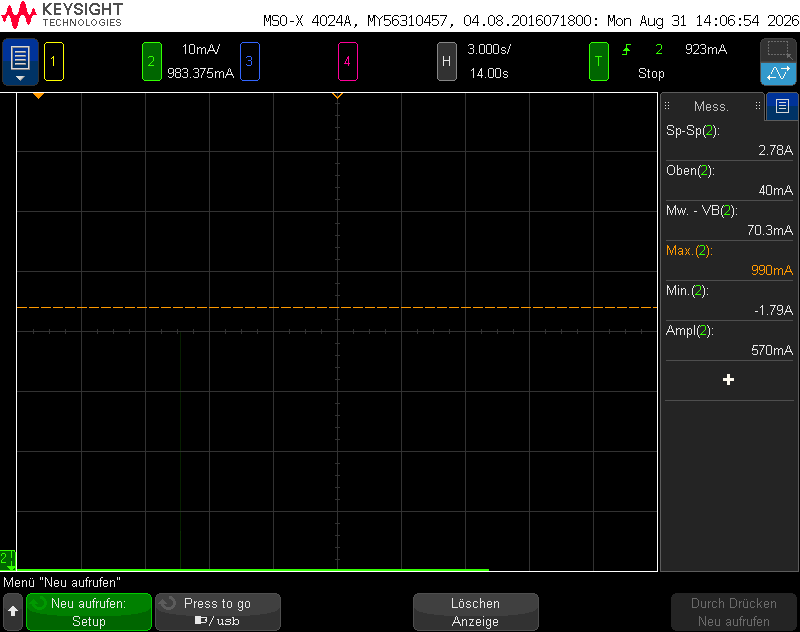
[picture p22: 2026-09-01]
Rohdaten Messung sofern aufgenommen/Messungen Faulhaber/faulhaber_fall_6.png

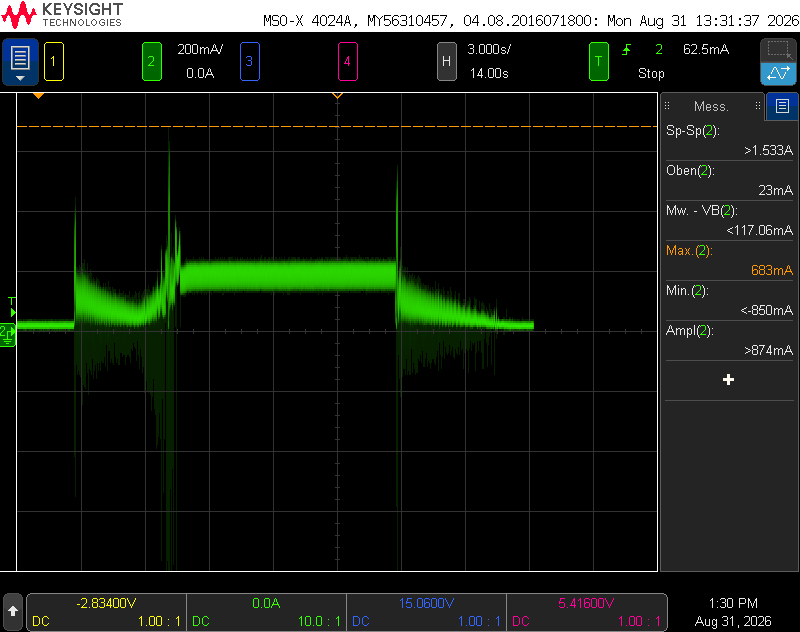
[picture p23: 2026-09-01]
Rohdaten Messung sofern aufgenommen/Messungen Faulhaber/faulhaber_fall_2.png

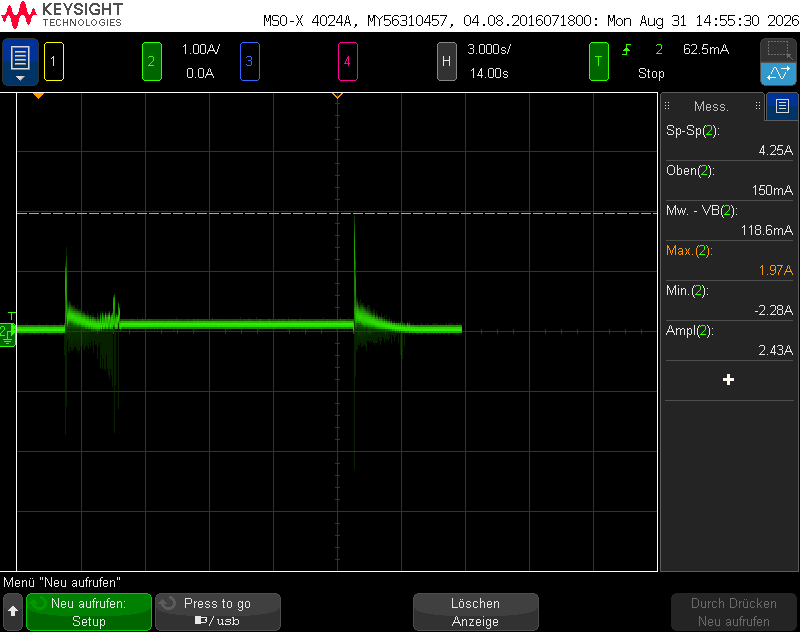
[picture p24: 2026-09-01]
Rohdaten Messung sofern aufgenommen/Messungen ACT/act_fall_7.png

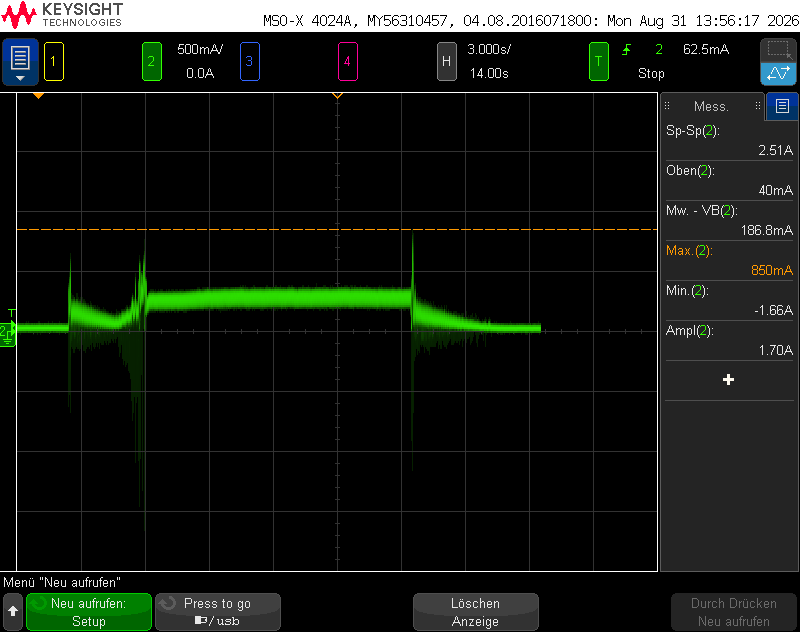
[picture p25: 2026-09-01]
Rohdaten Messung sofern aufgenommen/Messungen Faulhaber/faulhaber_fall_7.1.png

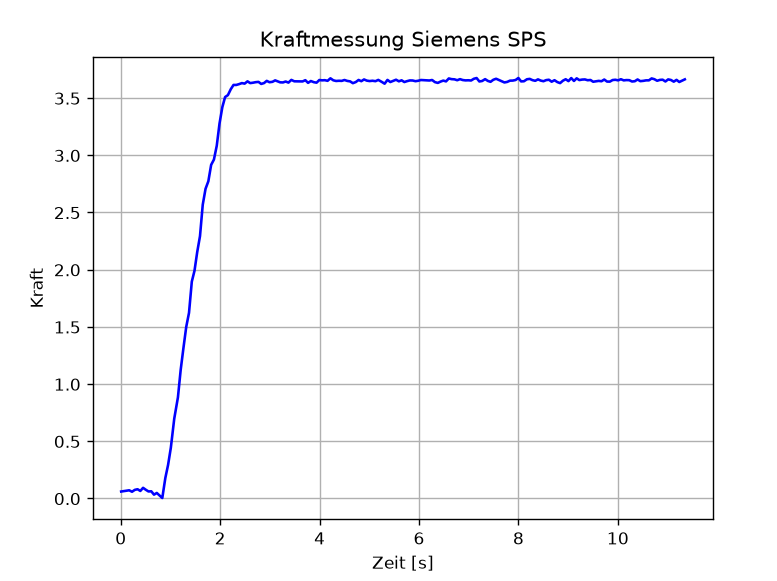
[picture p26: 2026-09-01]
Rohdaten Messung sofern aufgenommen/Messungen ACT/Messung 6 2026-08-27 114234.png

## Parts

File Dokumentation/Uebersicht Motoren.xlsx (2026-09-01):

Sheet: Übersicht Motoren
 |  | Übersicht Motoren
 | Wellendurchmesser | Hersteller | Bezeichnung | Preis (1x) | Polpaarzahl | Nennleistung | Webseite | Datenblatt | Bemerkungen
 | mm
80 W | 4 | Maxon | EC 45 Flat | 188.42 € | 8 | 80 W | Online-Shop für hochpräzise Antriebssysteme von maxon | maxon group (https://www.maxongroup.de/maxon/view/product/motor/ecmotor/ecflat/ecflat45/608144) | DE-290-2020.pdf (https://www.maxongroup.de/medias/sys_master/root/8839890436126/DE-290-2020.pdf)
Neu | 4 | Nanotec | DF45L024048-E | 188.90 € | 8 | 65 W | DF45L024048-E - Bürstenloser DC-Flachmotor mit … | Nanotec (https://www.nanotec.com/eu/de/produkte/10873-df45l024048-e) | DF45L024048-E (https://www.nanotec.com/fileadmin/files/Datenblaetter/BLDC/DF45/DF45L024048-E.pdf?1662643688)
 |  | Orbex | EC4527 | auf Anfrage | 8 | 62,2 W | EC4527 Flachbürstenloser Gleichstrommotor - Orbex Gruppe (https://orbexgroup.com/product/ec4527-flat-brushless-dc-motor/) | EC4527.pdf (https://orbex-group.s3.amazonaws.com/pdfs/flat-motors/EC4527.pdf)
 |  | Delta Line | 45BLW29-E | auf Anfrage | 8 | k.A. | 45BLW29-E 45BLW -E | Delta Line (https://www.delta-line.com/cat.pag/categoria-czk452kzpsxzk.html) | filedlw.php (https://www.delta-line.com/filedlw.php?id=3641)
 |  | Oyostepper | 45BLE27-24-01 | 121.60 € | 8 | 70 | Kaufen 45BLE27-24-01 Außenläufermotor 24V 4850 U/min 0.13 Nm 70W 3.6 A 3 Phasen Bürstenloser DC-Getriebemotor online - Oyostepper.de (https://www.oyostepper.de/goods-685-Au%C3%9Fenl%C3%A4ufermotor-24V-4850-Umin-013-Nm-70W-36-A-3-Phasen-B%C3%BCrstenloser-DC-Getriebemotor.html) | Vollständiges Datenblatt: 45BLE27-24-01.pdf (https://www.oyostepper.de/images/upload/File/45BLE27-24-01.pdf)
 |  | Servotechnica | SVTM F 03-0.130 | auf Anfrage | 8 | 66 W | Outrunner Flache BLDC-Motoren - Servotecnica (https://de.servotecnica.com/de/produkt/flache-bldc-motoren/) | SVTM-F-Series.pdf (https://de.servotecnica.com/wp-content/uploads/2025/12/SVTM-F-Series.pdf)
 | 5 | Faulhaber | 4221G024BXTH | auf Anfrage | 7 | 60 W | Motor mit integr. Elektronik Serie 4221 ... BXT H SC | FAULHABER (https://eshop.faulhaber.com/de/4221G024BXTH-SC/4221G024BXTH-SC) | DE_4221_BXTH_DFF.pdf (https://eshop.faulhaber.com/media/31/a0/f4/1775629961/DE_4221_BXTH_DFF.pdf)
 |  |  | 4221G024BXTR | auf Anfrage | 7 | 100 W | Bürstenloser DC-Motor Serie 4221 ... BXT R | FAULHABER (https://eshop.faulhaber.com/de/4221G024BXTR/4221G024BXTR) | DE_4221_BXTR_DFF.pdf (https://eshop.faulhaber.com/media/11/32/64/1775629963/DE_4221_BXTR_DFF.pdf)
 |  | PowerTronic | BL42.66H | auf Anfrage | k.A. | 77 W | BLDC-Motor Typ BL42.66H | PowerTronic (https://www.power-tronic.com/produkte/bldc-motoren/motoren-ohne-getriebe/bl42-66h/) | Typ-BL42-66H-2023-12-07.pdf (https://www.power-tronic.com/wp-content/uploads/2024/07/Typ-BL42-66H-2023-12-07.pdf)
>= 50W | 4 | Maxon | EC flat | 162.94 € | 8 | 50 W | Online-Shop für hochpräzise Antriebssysteme von maxon | maxon group (https://www.maxongroup.de/maxon/view/product/motor/ecmotor/ecflat/ecflat45/651610) | Datenblatt_ Maxon_EC45flat_50W.pdf
 |  | Delta Line | 45BLW21 | auf Anfrage | 8 | k.A. | 45BLW21 Wires 45BLW - wires | Delta Line (https://www.delta-line.com/a.pag/45blw21-wires--pzk3010kzczk301.html) | https://www.delta-line.com/filedlw.php?id=684
 |  | Orbex | EC 4527 | auf Anfrage | 8 | 70 W | EC4527 Flachbürstenloser Gleichstrommotor - Orbex Gruppe (https://orbexgroup.com/product/ec4527-flat-brushless-dc-motor/) | https://orbex-group.s3.amazonaws.com/pdfs/flat-motors/EC4527.pdf
 |  | Servotechnica | SVTM F 03-0.130 | auf Anfrage | 8 | 66W | Outrunner Flache BLDC-Motoren - Servotecnica (https://de.servotecnica.com/de/produkt/flache-bldc-motoren/) | SVTM-F-Series.pdf (https://de.servotecnica.com/wp-content/uploads/2025/12/SVTM-F-Series.pdf)
 |  | PowerTronic | BL43.26 | auf Anfrage | 8 | 50 W | BLDC-Motor Außenläufer Typ BL43 | PowerTronic (https://www.power-tronic.com/produkte/bldc-motoren/aussenlaeufer/bl43/) | Typ-BL43-2023-03-27.pdf (https://www.power-tronic.com/wp-content/uploads/2023/03/Typ-BL43-2023-03-27.pdf)
Low Budget |  | ACT Motor GmbH | 57BL03-1 | 23.95 € | 4 | 52 | ACT MOTOR DC-Motor bürstenlos, 24 V, 52 W, 16,5 Ncm | DC-Motoren günstig kaufen | reichelt elektronik (https://www.reichelt.de/de/de/shop/produkt/dc-motor_buerstenlos_24_v_52_w_16_5_ncm-271493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) | d:\Users\Desktop\57BL03-1æ−•æœ¯è§—æ€¼ä¹¦.exb (https://cdn-reichelt.de/documents/datenblatt/C300/57BL03-1.pdf)
Hobbybereich: |  | Servonaut | TM 72 | 30.60 € | k. A. | k. A. | Servonaut Online-Shop - Motor TM72 (https://www.servonaut.de/shop/de/product_info.php?info=p726_motor-tm72.html)

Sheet: Vergleich Bestellliste
 | Bestelliste |  |  |  |  |  |  |  |  |  |  |  | Maximum
 |  |  | KSE 3 | NSE-E mini 90-25 IOL |  |  |  |  |  |  | Bemerkungen |  | Minimum
 | Hersteller |  | Maxon (50W) | Maxon (50W) | Faulhaber | Faulhaber (48V) | Delta Line | Orbex | Orbex (48V) | ACT Motor GmbH
 | Modell |  | 651610 | 651613 | 4221G024BXT R | 4221G048BXT R | 45BLW21 | EC 4527 | EC 4527 | 57BL03-1 |  |  | "Ausreißer"
 | Teilenummer / Warennummer |  |  |  |  |  |  | 200011 | 200014 | 85011099
 | Webseite |  | Online-Shop für hochpräzise Antriebssysteme von maxon | maxon group (https://www.maxongroup.de/maxon/view/product/motor/ecmotor/ecflat/ecflat45/651610?etcc_cu=onsite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) | Online-Shop für hochpräzise Antriebssysteme von maxon | maxon group (https://www.maxongroup.de/maxon/view/product/motor/ecmotor/ecflat/ecflat45/651613) | Bürstenloser DC-Motor Serie 4221 ... BXT R | FAULHABER (https://eshop.faulhaber.com/de/4221G024BXTR/4221G024BXTR) | Bürstenloser DC-Motor Serie 4221 ... BXT R | FAULHABER (https://eshop.faulhaber.com/de/4221G024BXTR/4221G024BXTR) | 45BLW21 Wires 45BLW - wires | Delta Line (https://www.delta-line.com/a.pag/45blw21-wires--pzk3010kzczk301.html) | EC4527 Flat Brushless DC Motor - Orbex Group (https://orbexgroup.com/product/ec4527-flat-brushless-dc-motor/) | EC4527 Flat Brushless DC Motor - Orbex Group (https://orbexgroup.com/product/ec4527-flat-brushless-dc-motor/) | ACT MOTOR DC-Motor bürstenlos, 24 V, 52 W, 16,5 Ncm | DC-Motoren günstig kaufen | reichelt elektronik (https://www.reichelt.de/de/de/shop/produkt/dc-motor_buerstenlos_24_v_52_w_16_5_ncm-271493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) |  |  | Ausschlusskriterien
 | Datenblatt |  | DE-286-2020.pdf (https://www.maxongroup.de/medias/sys_master/root/8839889518622/DE-286-2020.pdf) | DE-286-2020.pdf (https://www.maxongroup.de/medias/sys_master/root/8839889518622/DE-286-2020.pdf) | DE_4221_BXTR_DFF.pdf (https://eshop.faulhaber.com/media/11/32/64/1775629963/DE_4221_BXTR_DFF.pdf) | DE_4221_BXTR_DFF.pdf (https://eshop.faulhaber.com/media/11/32/64/1775629963/DE_4221_BXTR_DFF.pdf) | filedlw.php (https://www.delta-line.com/filedlw.php?id=684) | EC4527.pdf (https://orbex-group.s3.amazonaws.com/pdfs/flat-motors/EC4527.pdf) | EC4527.pdf (https://orbex-group.s3.amazonaws.com/pdfs/flat-motors/EC4527.pdf) | 28 (https://cdn-reichelt.de/documents/datenblatt/C300/57BL03-1.pdf)
 |  |  |  |  |  |  |  |  |  |  |  | k. A. | keine Angabe
 | Alternative KSE 3 |  |  |  | FALSE | FALSE | FALSE | FALSE | FALSE | FALSE
 | Gründe f. Ausscheiden |  |  |  | 5er Welle / 16er Kragen | 6er Welle / 16er Kragen | 16er Kragen | Motorkörper zu lang | Motorkörper zu lang | zu groß
 | Alternative NSE-e mini 90-25 IOL |  |  |  | TRUE | TRUE | TRUE | FALSE | FALSE | FALSE
 | Gründe f. Ausscheiden |  |  |  | (16er Kragen) | (16er Kragen) | (16er Kragen) | Motorkörper zu lang | Motorkörper zu lang | zu groß
 | Polpaarzahl |  | 8.00 | 8.00 | 7.00 | 7.00 | 8.00 | 8.00 | 8.00 | 4.00 | evtl. unruiger Lauf durch geringe Polpaarzahl
 | Phasen |  | 3.00 | 3.00 | 3.00 | 3.00 | 3.00 | 3.00 | 3.00 | 3.00
 | Gewicht | g | 116.40 | 116.40 | 127.00 | 127.00 | 120.00 | 141.00 | 141.00 | 550.00
 | Hallsensoren (über Signale auslesbar) |  | TRUE | TRUE | TRUE | TRUE | TRUE | TRUE | TRUE | TRUE
 | Anlaufstrom | A | 40.00 | 13.00 | k.A. | k.A. | k. A. | k. A. | k. A. | k. A.
Leerlaufwerte:
 | Leerlaufdrehzahl |  | 5740.00 | 5740.00 | 5960.00 | 6070.00 | k. A. | 6110.00 | 3440.00 | 4000
 | Leerlaufstrom | mA | 277.00 | 104.00 | 186.00 | 74.00 | 380.00 | 400.00 | 112.00 | k. A. | höhere Leerlaufströme durch 24V Betrieb
Nennwerte:
 | Nennspannung | V | 18.00 | 48.00 | 24.00 | 48.00 | 24.00 | 24.00 | 48.00 | 24.00 | 24V statt 48V
 | Nennstrom | A | 3.68 | 1.27 | 3.17 | 1.66 | 2.55 | 3.21 | 0.94 | 3.00 | höherer Strom im Arbeitspunkt
 | Nennleistung | W | 50.00 | 50.00 | 100.00 | 100.00 | k. A. | 70.00 | 70.00 | 52.00
 | Nenndrehzahl |  | 4690.00 | 4710.00 | 4180.00 | 4390.00 | 5260.00 | 4860.00 | 2500.00 | 3000.00
 | Nennmoment | mNm | 112.00 | 102.00 | 127.00 | 134.00 | 84.00 | 128.00 | 134.00 | 165.00
 | Maximalsotrm | A | k. A. | k. A. | k.A. | k.A. | 7.00 | 39.50 | 7.00 | 9.00
 | Maximaldrehmoment | mNm | k. A. | k. A. | k.A. | k.A. | 250.00 | 1150.00 | 897.00 | 580.00
 | Wirkungsgrad | % | 84.40 | 83.40 | 87.00 | 88.00 | k. A. | 85.00 | 84.00 | k. A.
Anschlusswerte:
 | Anschlusswiderstand | mΩ | 447.00 | 3610.00 | 740.00 | 2600.00 | 800.00 | 550.00 | 6890.00 | 820.00 | kleinerer Widerstand zwischen den Phasen durch 24V betrieb
 | Anschlussimdiktivität | µH | 243.00 | 1730.00 | 664.00 | 2550.00 | 330.00 | 220.00 | 3120.00 | k. A. | kleinere Induktivität => kleinerer Blindwiderstand zwischen den Phasen durch 24V betrieb benötigt
Konstanten:
 | Drehmomentkonstante | mNm/A | 29.50 | 78.60 | 37.70 | 75.20 | 33.00 | 37.17 | 131.10 | 61.00
 | Drehzahlkonstante |  | 324.00 | 121.00 | 253.00 | 127.00 | k. A. | 257.00 | 73.00 | 156.25
 | Steigung der n/M-Kennlinie |  | 4.91 | 5.58 | 4.97 | 4.40 | k. A. | 5.31 | 3.84 | k. A.
 | Mechanische Anlaufzeit | ms | 6.94 | 7.89 | 3.59 | 3.18 | k. A. | 8.10 | 7.20 | k. A.
 | Rotorträgheitsmoment |  | 135.00 | 135.00 | 69.00 | 69.00 | 135.00 | 181.00 | 181.00 | k. A.
Temperaturen:
 | Therm. Widerstand (ges.) | K/W | 9.95 | 9.95 | k.A. | k.A. | k. A. | k. A. | k. A. | k. A.
 | Therm. Zeitkonstante Motor | s | 78.30 | 78.30 | k.A. | k.A. | k. A. | k. A. | k. A. | k. A.
 | Therm. Zeitkonstante Wicklung | s | 28.80 | 28.80 | k.A. | k.A. | k. A. | k. A. | k. A. | k. A.
 | Umgebungstemperatur min. | °C | -40.00 | -40.00 | -40.00 | -40.00 | k. A. | -40.00 | -40.00 | k. A.
 | Umgebungstemperatur max. | °C | 100.00 | 100.00 | 100.00 | 100.00 | k. A. | 100.00 | 100.00 | k. A.
 | Wicklungstemperatur max. | °C | 125.00 | 125.00 | 125.00 | 125.00 | k. A. | 125.00 | 125.00 | k. A.
Bauraum:
 | Grenzdrehzal |  | 10000.00 | 10000.00 | 10000.00 | 10000.00 | k. A. | 10000.00 | 10000.00 | k. A.
 | max.Durchmesser Motorkörper | mm | 43.50 | 43.50 | 42.00 | 42.00 | 43.20 | 42.00 | 42.00 | 57.00
 | Länge Motrkörper | mm | 22.00 | 22.00 | 21.20 | 21.20 | 21.00 | 26.70 | 26.70 | 56.50 | Orbex Motorkörper zu lang!
 | Durchmesser Welle | mm | 4.00 | 4.00 | 5.00 | 5.00 | 4.00 | 4.00 | 4.00 | 8.00
 | Länge Welle | mm | 20.00 | 20.00 | 11.50 | 11.50 | 17.40 | 6.80 | 6.80 | 23.00 | Orbex extremkurze Welle!
 | Länge über Alles | mm | 42.00 | 42.00 | 34.20 | 34.20 | 41.60 | 36.70 | 36.70 | 81.50
 | "Kragendurchmesser" | mm | 12.00 | 12.00 | 16.00 | 16.00 | 16.00 | 12.00 | 12.00 | 25.00
Hilfsgrößen:
 | Überstand Zentrierring | mm | 0.30 | 0.30 | 0.30 | 0.30 | 0.30 | 0.30 | 0.30 | 0.00
 | Länge NSE-E mini Flansch über Getriebe | mm | 82.70 | 82.70 | 82.70 | 82.70 | 82.70 | 82.70 | 82.70 | 82.70
 | Materalstärke "Boden" | mm | 17.00 | 17.00 | 17.00 | 17.00 | 17.00 | 17.00 | 17.00 | 17.00
 | resultierende Stützenläge | mm | 66.00 | 66.00 | 66.00 | 66.00 | 66.00 | 66.00 | 66.00 | 65.70
 | Preis (netto) | € | 162.94 | 162.94 | 242.60 | 350.00 | 150.00 | 120.00 | 121.00 | 23.95
 |  | auf Anfrage | TRUE | TRUE | FALSE | FALSE | TRUE | TRUE | TRUE | FALSE
 |  |  |  |  |  |  | geschäzt laut Gemini | geschäzt laut Gemini | geschäzt laut Gemini
 | Onlineshop |  |  |  | Bürstenloser DC-Motor Serie 4221 ... BXT R | FAULHABER (https://eshop.faulhaber.com/de/4221G024BXTR-6862/4221G024BXTR-6862) | 4221G024BXT R | Faulhaber 4221 Servomotor, 127 mNm, 24V, 4180U/min, 100 W, 0.12 Nm, 5 mm, B. 42mm, T. 47 mm, L. 34.2 mm, L. 11.5 mm | RS (https://at.rs-online.com/web/p/servomotoren/1846937) | 45BLW21 Wires 45BLW - wires | Delta Line (https://www.delta-line.com/a.pag/45blw21-wires--pzk3010kzczk301.html) | EC4527 Flat Brushless DC Motor - Orbex Group (https://orbexgroup.com/product/ec4527-flat-brushless-dc-motor/) | EC4527 Flat Brushless DC Motor - Orbex Group (https://orbexgroup.com/product/ec4527-flat-brushless-dc-motor/) | ACT MOTOR DC-Motor bürstenlos, 24 V, 52 W, 16,5 Ncm | DC-Motoren günstig kaufen | reichelt elektronik (https://www.reichelt.de/de/de/shop/produkt/dc-motor_buerstenlos_24_v_52_w_16_5_ncm-271493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)
 | Bestellt |  | FALSE | FALSE | TRUE | FALSE | TRUE | FALSE | FALSE | TRUE
 |  |  | 0.00 € | 0.00 € | 242.60 € | 0.00 € | 150.00 € | 0.00 € | 0.00 € | 23.95 €
 | Gesammtpreis (netto) | 416.55 €

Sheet: Vergleich Maxon 80W
Vergleichbare Motoren zum Maxon 608144 (80 W) (60 W - 100W)
 |  | Wellendurchmesser 4mm |  |  |  |  |  | Wellendurchmesser 5mm
Hersteller |  | Maxon (80W) | Deltaline | Nanotec | Orbex | Oyostepper | Servotechnica | Faulhaber | Faulhaber | Powertronic | zusammengefasst (ohne Maxon Motor):
Modell |  | 608144 | 45BLW29-E | DF45L024048-E | EC 4527 | 45BLE27-24-01 | SVTM F 03-0.130 | 4221G024BXT H | 4221G024BXT R | BL42.66H
Teilenummer (fals vorhanden) |  |  |  |  | 200011 |  |  |  |  |  | *** bis ***
Alternative KSE 3 |  |  | FALSE | FALSE | TRUE | FALSE | FALSE | FALSE | TRUE | FALSE
Alternative NSE-e mini 90-25 IOL |  |  | FALSE | FALSE | TRUE | FALSE | FALSE | FALSE | TRUE | FALSE
Polpaarzahl |  | 8.00 | 8.00 | 8.00 | 8.00 | 8.00 | 8.00 | 7.00 | 7.00 | k.A. | 7 oder 8
Phasen |  | 3.00 | 3.00 | 3.00 | 3.00 | 3.00 | 3.00 | 3.00 | 3.00 | k.A. | 3
Gewicht | g | 147.10 | 160.00 | 160.00 | 141.00 | 150.00 | 150.00 | 142.00 | 127.00 | 360.00 | 127 bis 160 (360)
Hallsensoren (über Signale auslesbar) |  | TRUE | TRUE | TRUE | TRUE | TRUE | TRUE | TRUE | TRUE | TRUE | TRUE
Anlaufstrom | A | 42.00 | k.A. | k.A. | k.A. | k.A. | k.A. | k.A. | k.A. | k.A. | k.A.
Leerlaufdrehzahl |  | 5600.00 | k.A. | 6100.00 | 6110.00 | 6100.00 | 6100.00 | 6040.00 | 5960.00 | 4000.00 | 4000 bis 6110
Leerlaufstrom | mA | 270.00 | 500.00 | 500.00 | 400.00 | 500.00 | 0.50 | 139.00 | 186.00 | 500.00 | 139mA bis 500mA
Nennspannung | V | 24.00 | 24.00 | 24.00 | 24.00 | 24.00 | 24.00 | 24.00 | 24.00 | 24.00 | 24,00V
Nennstrom | A | 3.96 | 3.50 | 3.50 | 3.21 | 3.60 | 3.26 | 2.78 | 3.17 | 4.50 | 2,78A bis 4,50A
Nennleistung | W | 80.00 | k.A. | 65.00 | 62.50 | 70.00 | 66.00 | 60.00 | 100.00 | 77.00 | 60W bis 100 W
Nenndrehzahl |  | 4560.00 | 4840.00 | 4840.00 | 4860.00 | 4850.00 | 4840.00 | 4380.00 | 4180.00 | 3000.00 | 3000 bis 4860
Nennmoment | mNm | 167.00 | 130.00 | 130.00 | 128.00 | 130.00 | 130.00 | 112.00 | 127.00 | 250.00 | 112mNm bis 250mNm
Maximalsotrm | A | k.A. | 10.00 | 10.00 | 39.50 | k.A. | 9.50 | k.A. | k.A. | k.A. | 9,5A bis 39,5A
Maximaldrehmoment | mNm | k.A. | 390.00 | 390.00 | 1150.00 | k.A. | 390.00 | k.A. | k.A. | k.A. | 1150mNm bis 390 mNm
Wirkungsgrad | % | 84.90 | k.A. | k.A. | 85.00 | k.A. | k.A. | 87.00 | 87.00 | 85.00 | 85% oder 87%
Anschlusswiderstand | mΩ | 573.00 | 560.00 | 560.00 | 550.00 | 560.00 | 560.00 | 740.00 | 740.00 | k.A. | 550Ω bis 740Ω
Anschlussimdiktivität | µH | 301.00 | 270.00 | 270.00 | 220.00 | 270.00 | 270.00 | 664.00 | 664.00 | k.A. | 220µH bis 664µH
Drehmomentkonstante | mNm/A | 40.40 | 37.00 | 36.90 | 37.17 | 37.20 | 36.90 | 37.70 | 37.70 | k.A. | 36,90mNm bis 37,70mNm
Drehzahlkonstante |  | 236.00 | k.A. | k.A. | 257.00 | k.A. | k.A. | 1000.00 | 253.00 | k.A.
Kennliniensteigung |  | 3.35 | k.A. | k.A. | 5.31 | k.A. | k.A. | 4.97 | 4.97 | k.A.
Mechanische Anlaufzeit | ms | 6.35 | k.A. | k.A. | 8.10 | k.A. | k.A. | 3.59 | 3.59 |  | 3,59ms oder 8,10ms
Rotorträgheitsmoment |  | 181.00 | 181.00 | 181.00 | 181.00 | 181.00 | 181.00 | 69.00 | 69.00
Therm. Widerstand (ges.) | K/W | 6.54 | k.A. | k.A. | k.A. | k.A. | k.A. | k.A. | k.A. | k.A. | k.A.
Therm. Zeitkonstante Wicklung | s | 34.00 | k.A. | k.A. | k.A. | k.A. | k.A. | k.A. | k.A. | k.A. | k.A.
Umgebungstemperatur min. | °C | -40.00 | k.A. | -20.00 | -40.00 | -20.00 | -25.00 | -40.00 | -40.00 | k.A. | -40°C bis-20°C
Umgebungstemperatur max. | °C | 100.00 | k.A. | 55.00 | 100.00 | 50.00 | 55.00 | 100.00 | 100.00 | k.A. | 50°C bis 100°C
Wicklungstemperatur max. | °C | 125.00 | k.A. | 80.00 | 125.00 | 80.00 | k.A. | 125.00 | 125.00 | k.A. | 80°C oder 125°C
Grenzdrehzal |  | 10000.00 | k.A. | k.A. | 10000.00 | k.A. | k.A. | 10000.00 | 10000.00 | k.A.
max.Durchmesser Motorkörper | mm | 43.50 | 45.00 | 45.00 | 42.00 | 43.20 | 43.20 | 42.00 | 42.00 | 42.40 | 42mm bis 45mm
Länge Motrkörper | mm | 27.00 | 29.00 | 29.00 | 26.70 | 27.00 | 27.00 | 28.00 | 21.20 | 66.00 | 21,20mm bis 29mm (66mm)
Durchmesser Welle | mm | 4.00 | 4.00 | 4.00 | 4.00 | 4.00 | 4.00 | 5.00 | 5.00 | 5.00 | 4mm oder 5mm
Länge Welle | mm | 16.80 | 17.40 | 17.40 | 6.80 | 17.40 | 17.40 | 11.50 | 11.50 | 13.00 | 6,80mm bis 17,40mm
Länge über Alles | mm | 47.00 | 46.60 | 46.60 | 36.70 | 44.40 | 47.60 | 41.00 | 34.20 | 81.00 | 34,20mm bis 47,60mm (81mm)
"Kragendurchmesser" | mm | 12.00 | 16.00 | 16.00 | 12.00 | 12.00 | 16.00 | 16.00 | 16.00 | 17.50 | 12,00mm oder 16mm (17,50mm)

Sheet: Vergleich Maxon 50W
Vergleichbare Motoren zum Maxon 651610 / 651613 (50 W) [Maßangaben ohne Tolleranzen]
 | Wellendurchmesser 4mm |  |  |  |  |  |  | Motoren unter 50€
 |  | KSE 3 | NSE-E mini 90-25 IOL
Hersteller |  | Maxon (50W) | Maxon (50W) | Delta Line | Orbex | Servotechnica | PowerTronic | ACT Motor GmbH
Modell |  | 651610 | 651613 | 45BLW21 | EC 4527 | SVTM F 03-0.130 | BL43.26 | 57BL03-1
Teilenummer / Warennummer |  |  |  |  | 200011 |  |  | 85011099
Alternative KSE 3 |  |  |  | FALSE | TRUE | FALSE | FALSE | FALSE
Alternative NSE-e mini 90-25 IOL |  |  |  | TRUE | TRUE | TRUE | TRUE | FALSE
Polpaarzahl |  | 8.00 | 8.00 | 8.00 | 8.00 | 8.00 | 8 | 4.00
Phasen |  | 3.00 | 3.00 | 3.00 | 3.00 | 3.00 | 3 | 3.00
Gewicht | g | 116.40 | 116.40 | 120.00 | 141.00 | 150.00 | 180 | 550.00
Hallsensoren (über Signale auslesbar) |  | TRUE | TRUE | TRUE | TRUE | TRUE | TRUE | TRUE
Anlaufstrom | A | 40.00 | 13.00 | k. A. | k.A. | k.A. | k.A. | k.A.
Leerlaufdrehzahl |  | 5740.00 | 5740.00 | k. A. | 6110.00 | 6100.00 | k.A. | k.A.
Leerlaufstrom | mA | 277.00 | 104.00 | 380.00 | 400.00 | 0.50 | k.A. | 4000.00
Nennspannung | V | 18.00 | 48.00 | 24.00 | 24.00 | 24.00 | 24.00 | 24.00
Nennstrom | A | 3.68 | 1.27 | 2.55 | 3.21 | 3.26 | 3.20 | 3.00
Nennleistung | W | 50.00 | 50.00 | k. A. | 62.50 | 66.00 | 50.00 | 52.00
Nenndrehzahl |  | 4690.00 | 4710.00 | 5260.00 | 4860.00 | 4840.00 | 5000.00 | 3000.00
Nennmoment | mNm | 112.00 | 102.00 | 84.00 | 128.00 | 130.00 | 100.00 | 165.00
Maximalsotrm | A | k. A. | k. A. | 7.00 | 39.50 | 9.50 | 9.60 | 9.00
Maximaldrehmoment | mNm | k. A. | k. A. | 250.00 | 1150.00 | 390.00 | 300.00 | 580.00
Wirkungsgrad | % | 84.40 | 83.40 | k. A. | 85.00 | k.A. | k.A. | k.A.
Anschlusswiderstand | mΩ | 447.00 | 3610.00 | 800.00 | 550.00 | 560.00 | 1500.00 | 820.00
Anschlussimdiktivität | µH | 243.00 | 1730.00 | 330.00 | 220.00 | 270.00 | 1000.00 | k.A.
Drehmomentkonstante | mNm/A | 29.50 | 78.60 | 33.00 | 37.17 | 36.90 | 3.00 | 61.00
Drehzahlkonstante |  | 324.00 | 121.00 | k. A. | 257.00 | k.A. | k.A. | 15.63
Kennliniensteigung |  | 4910.00 | 5580.00 | k. A. | 5.31 | k.A. | k.A. | k.A.
Mechanische Anlaufzeit | ms | 6.94 | 7.89 | k. A. | 8.10 | k.A. | k.A. | k.A.
Rotorträgheitsmoment |  | 135.00 | 135.00 | 135.00 | 181.00 | 181.00 | 230.00 | k.A.
Therm. Widerstand (ges.) | K/W | 9.95 | 9.95 | k. A. | k.A. | k.A. | k.A. | k.A.
Therm. Zeitkonstante Motor | s | 78.30 | 78.30 | k. A. | k.A. | k.A. | k.A. | k.A.
Therm. Zeitkonstante Wicklung | s | 28.80 | 28.80 | k. A. | k.A. | k.A. | k.A. | k.A.
Umgebungstemperatur min. | °C | -40.00 | -40.00 | k. A. | -40.00 | -25.00 | -20.00 | k.A.
Umgebungstemperatur max. | °C | 100.00 | 100.00 | k. A. | 100.00 | 55.00 | 55.00 | k.A.
Wicklungstemperatur max. | °C | 125.00 | 125.00 | k. A. | 125.00 | k.A. | k.A. | k.A.
Grenzdrehzal |  | 10000.00 | 10000.00 | k. A. | 10000.00 | k.A. | k.A. | k.A.
max.Durchmesser Motorkörper | mm | 43.50 | 43.50 | 43.20 | 42.00 | 43.20 | 42.80 | 57.00
Länge Motrkörper | mm | 22.00 | 22.00 | 21.00 | 26.70 | 27.00 | 26.30 | 56.50
Durchmesser Welle | mm | 4.00 | 4.00 | 4.00 | 4.00 | 4.00 | 4.00 | 8.00
Länge Welle | mm | 20.00 | 20.00 | 17.40 | 6.80 | 17.40 | 17.50 | 23.00
Länge über Alles | mm | 42.00 | 42.00 | 41.60 | 36.70 | 47.60 | 46.30 | 81.50
"Kragendurchmesser" | mm | 12.00 | 12.00 | 16.00 | 12.00 | 16.00 | 22.00 | 25.00
Preis | € |  |  |  |  |  |  | 23.95

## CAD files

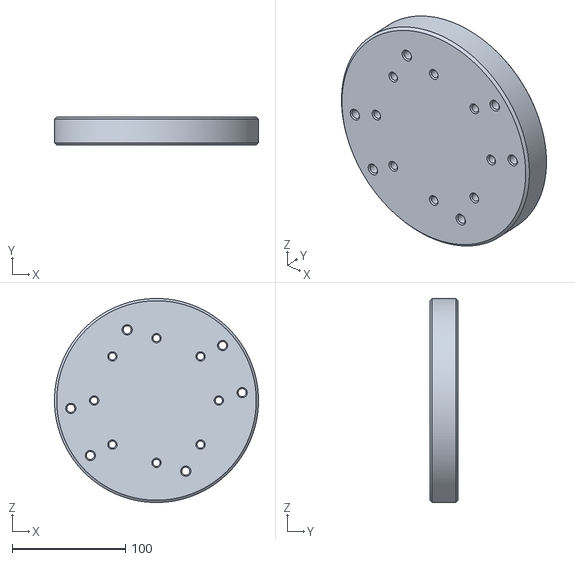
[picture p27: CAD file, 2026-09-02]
3D Druckdateien Vorrichtung/grundplatte_1x.stl
180.0 x 25.0 x 180.0

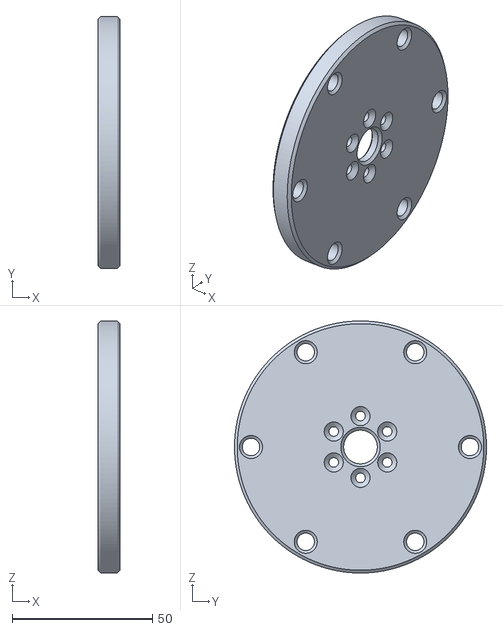
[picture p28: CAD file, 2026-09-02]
3D Druckdateien Vorrichtung/halter_orbex_1x.stl
8.00 x 89.8 x 89.8

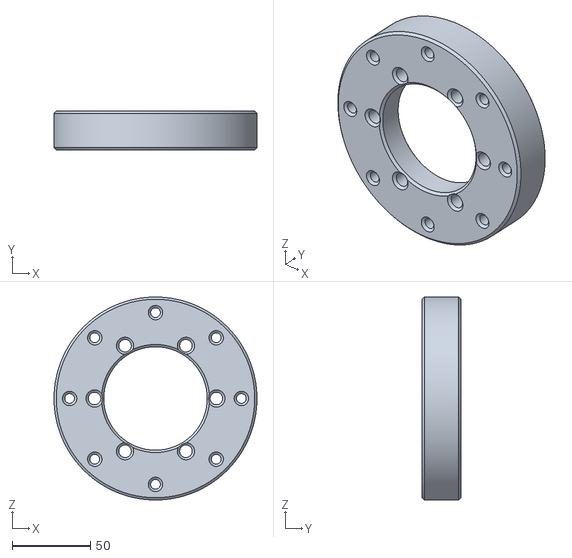
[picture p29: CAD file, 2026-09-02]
3D Druckdateien Vorrichtung/halter_nse-e_motorscheiben_r_2x.stl
130.0 x 25.0 x 130.0

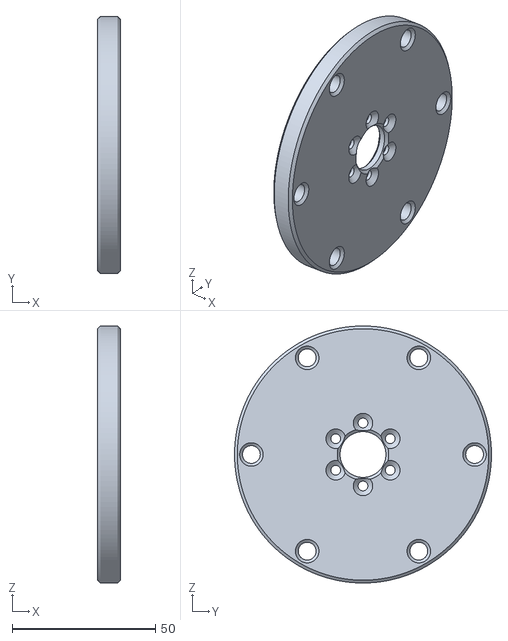
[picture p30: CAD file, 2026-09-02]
3D Druckdateien Vorrichtung/halter_faulhaber_deltaline_2x.stl
8.00 x 89.8 x 89.8

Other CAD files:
3D Druckdateien Vorrichtung/halter_maxon_1x.stl
3D Druckdateien Vorrichtung/halter_act_motor_neu_1x.stl

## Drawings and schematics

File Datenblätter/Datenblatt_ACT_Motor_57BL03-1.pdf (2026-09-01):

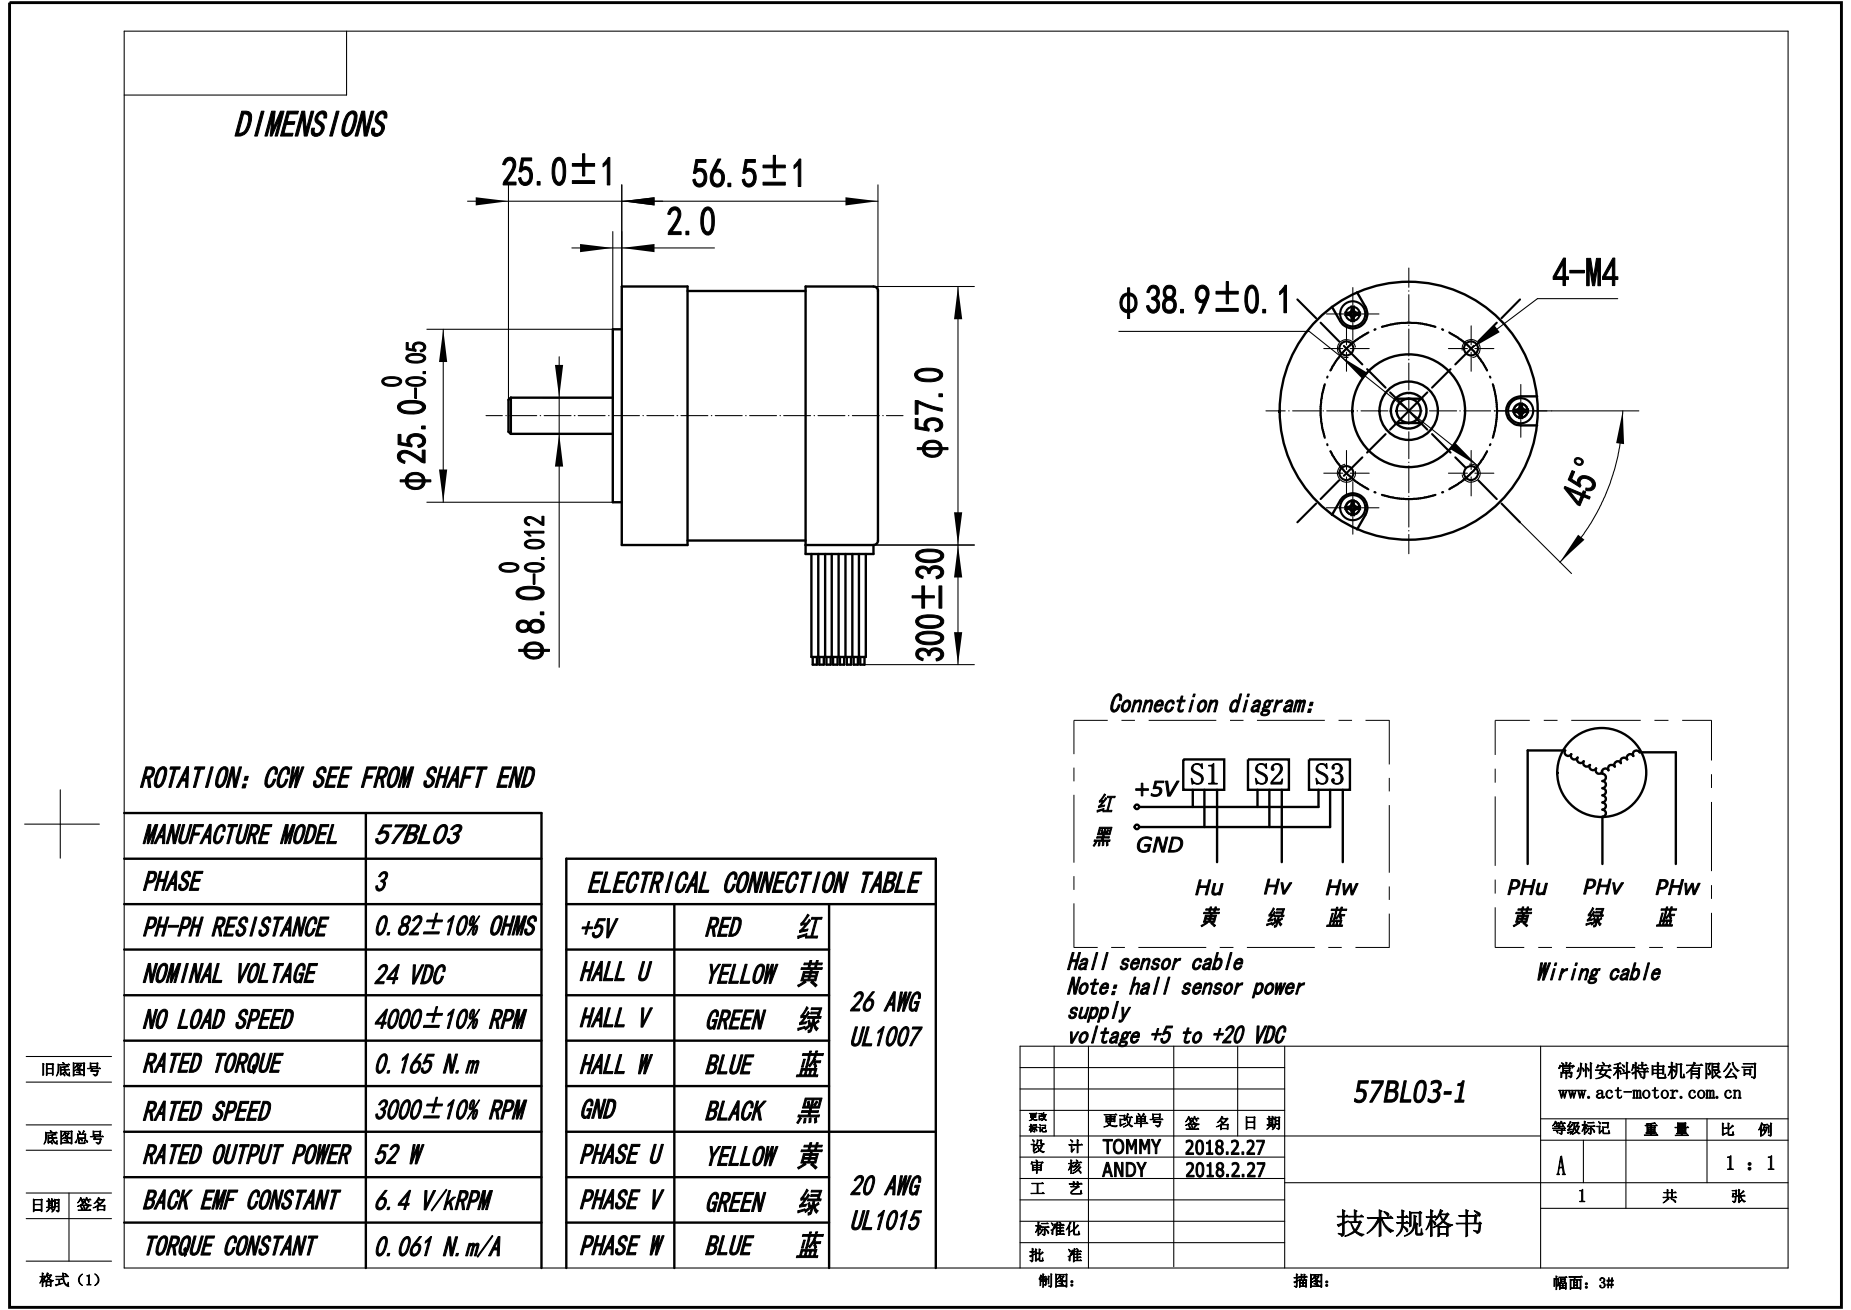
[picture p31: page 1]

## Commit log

2026-08-19 test_epos.py: Speicherort der Library als Variable
2026-08-20 self in Funktionen des Controlers nachgetragen
2026-08-21 Positionsdaten über Motor und Positionswahl
2026-08-21 eingabeparameter um Motorbewegung erweitert
2026-08-26 Sensor auslesen funktioniert
2026-08-26 motor fährt nicht mehr auf wechsel
2026-09-01 zwischencommit änderung Ordnerstruktur
    [Uebersicht Motoren.xlsx, prt0001.stl, Übersicht Parameter Messungen.xlsx]
2026-09-02 3D Druckteile angegeben
    [grundplatte_1x.stl, halter_act_motor_neu_1x.stl, halter_faulhaber_deltaline_2x.stl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]
2026-09-02 3D-Pdf von der Vorrichtung
2026-09-03 Dokumentation aktualisiert
    [Übersicht Parameter Messungen.xlsx]
